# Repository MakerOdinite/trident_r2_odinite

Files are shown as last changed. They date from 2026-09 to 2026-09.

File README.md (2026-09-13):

# Trident R2 Odinite ⚙️

Trident LDO 300 cube mod build.

---

## What This Is

* **The Origin**: Years ago I bought an LDO Voron Trident 300 cube kit from Fabreeko.
* **The Delay**: Life happened and it sat in storage for a bit (3 and a half years is a bit, right?).
* **The Goal**: Figured it was time to build it, and mod it before I build—"do it nice, not twice." I want a stable printer for ABS, ASA, and multi-material printing.
* **The Solution**: Decided to go all-in on a Bondtech INDX system.
* **This Repo**: Born as a place for me to virtually build it before I really build it, and to serve as a permanent record of the build process.

---

## Submodules

* **[Official Voron Trident R2](https://github.com/VoronDesign/Voron-Trident)** (from 2026-06-26)  
  Commit: `f04f747d4dea06315806f352abf57f767cedf2b4`
* **[Clicky Clack Door](https://github.com/tanaes/whopping_Voron_mods.git)** (from 2024-08-26)  
  Commit: `62268ed817878e54d6a1186882060aa8368d4f0f`  
  *Hardware Kit:* [West3D Clicky Clack Fridge Door Kit](https://west3d.com/products/clicky-clack-fridge-door-kit-for-voron-trident-by-ldo-motors)

---

## Other Folders

**ldo_kit_info**: original build information regarding my base kit
**stealthpress_1s**: I'm going to do a lot of brass inserts... so I'm investing in this 

---

## Planned Mods & Hardware Changes

These changes were driven by what I had available and what I was able to source to support my stable ABS/ASA design goals:

| Category | Component / Mod Details |
| :--- | :--- |
| **Motion & Motors** | Change AB motors to longer shafts (`OMC 17HS19-2504S-H-V6`) |
| **Toolhead** | Bondtech INDX with 7 tools |
| **Enclosure & Frame** | ACM panels, titanium rail backers, and PEEK Z-axis lead screw nuts |
| **Cooling & Filtration** | Stealthmax V2 (top intake, bottom recirculation), dual 120mm underbed chamber circulators, and active AB stepper coolers |
| **Electronics & Power** | BTT Manta M8P V2 MCU, Raspberry Pi CM5 (with copper heatspreader, a 4011 heatsink, and custom fan cooling), Mean Well RSP-320-24 PSU, and BTT TMC5160 Pro stepper drivers (cooled with 5015 Delta fans) |
| **User Interface & Misc** | BTT HDMI5 touchscreen, chamber LEDs, and "Rock and Roller" mod for easy bottom access |

---

## Mods Considered (and Passed On)

* **Inverted Electronics Bay**: Passed on this because I didn't want loose parts or debris falling down directly into the electronics bay during maintenance.

---

## TODO

- [ ] Double-check endstops (prefer mechanical, normally closed `NC` fail-safe wiring, Omron, no lever)
- [ ] Install Chamber LEDs and status light bar
- [ ] Design/print a custom Tophat to clear the PTFE tubes
- [ ] Design/mount a camera mount
- [ ] Configure ethernet over Wi-Fi

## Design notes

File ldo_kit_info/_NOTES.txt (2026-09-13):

LDO kit matches a batch 2 release, without included Pi and 32GB sd card instead of 16GB.

Minimized pdf with ghostscript:
gs --% -sDEVICE=pdfwrite -dCompatibilityLevel=1.4 -dColorConversionStrategy=/LeaveColorUnchanged -dBlendConversionStrategy=/None -dDownsampleColorImages=true -dDownsampleGrayImages=true -dDownsampleMonoImages=true -dColorImageResolution=300 -dGrayImageResolution=300 -dMonoImageResolution=300 -dColorImageDepth=-1 -dGrayImageDepth=-1 -dMonoImageDepth=-1 -dAutoFilterColorImages=false -dAutoFilterGrayImages=false -dColorImageFilter=/FlateEncode -dGrayImageFilter=/FlateEncode -dNOPAUSE -dQUIET -dBATCH -sOutputFile="LDO Voron Trident 300 Wiring Guide (Rev. A_C) _ LDO Documentation.pdf" "LDO Voron Trident 300 Wiring Guide (Rev. A_C) _ LDO Documentation_big.pdf"

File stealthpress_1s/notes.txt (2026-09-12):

downloaded on 2026-09-12 from:
https://www.printables.com/model/1081157-stealth-press-1s-heat-set-insert-press

converted to make video much smaller:
ffmpeg -i '.\Stealth Press 1S build guide [reMUZEUkHd0].webm' -vf "scale=-2:480" -r 30 -c:v libx265 -preset slow -crf 26 -pix_fmt yuv420p -c:a aac -ar 16000 -b:a 48k stealthpress1s_assembly.mp4

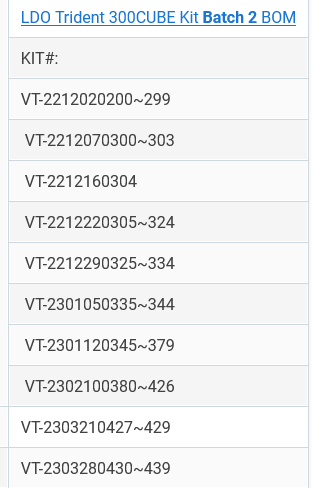
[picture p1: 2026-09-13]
ldo_kit_info/serial_batch_match_vt-2301120373.png

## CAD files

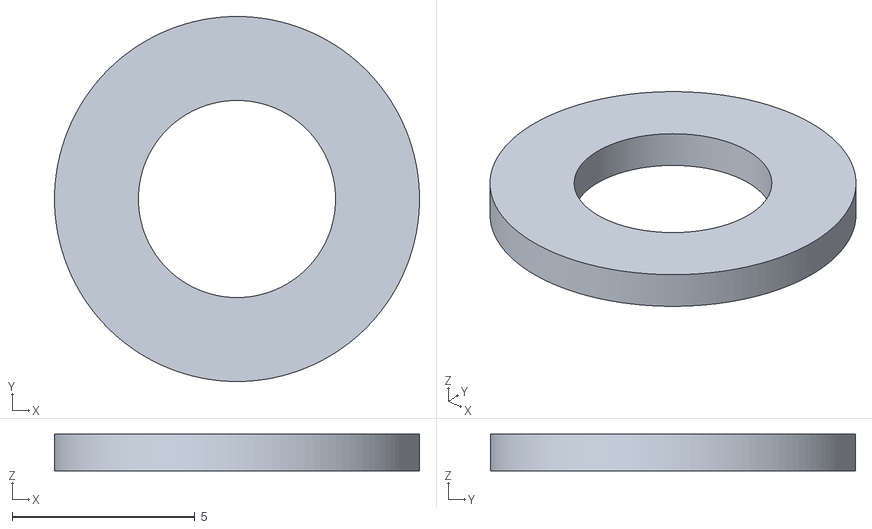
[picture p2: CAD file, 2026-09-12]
stealthpress_1s/stl from printables/a_m5_1mm_spacer_x4_r1s.stl
10.00 x 10.0 x 1.00

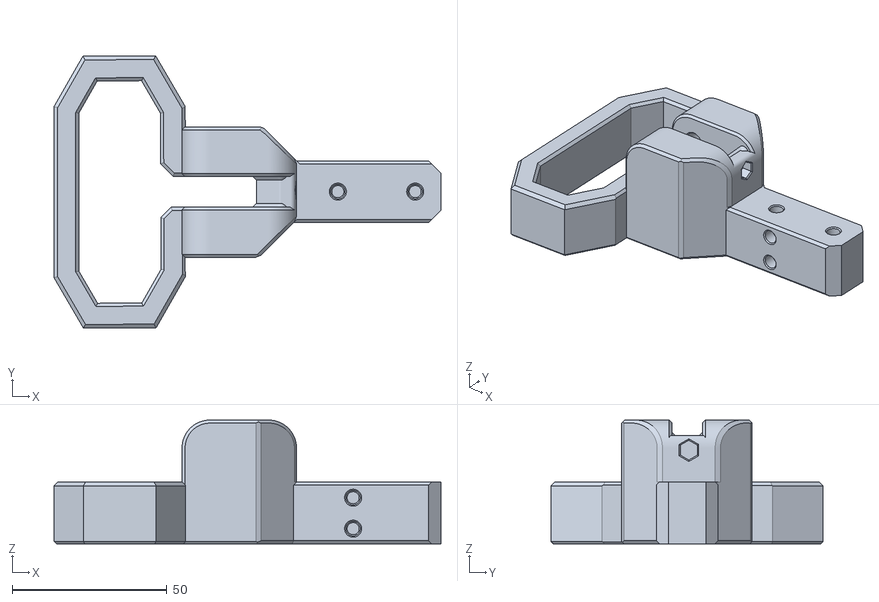
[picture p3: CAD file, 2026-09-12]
stealthpress_1s/stl from printables/top_handle_x1_r1s.stl
125.1 x 88.0 x 40.0

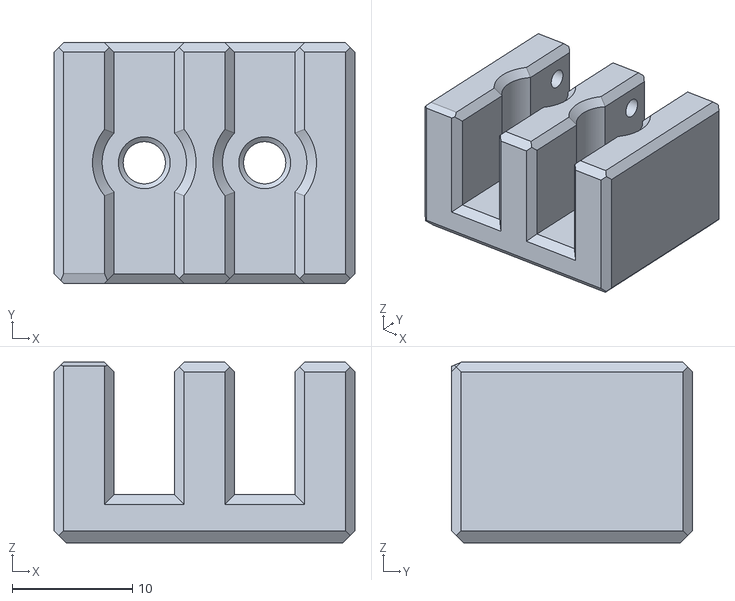
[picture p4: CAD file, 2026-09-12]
stealthpress_1s/stl from printables/a_strain_relief_r_x1_r1s.stl
25.0 x 20.0 x 15.0

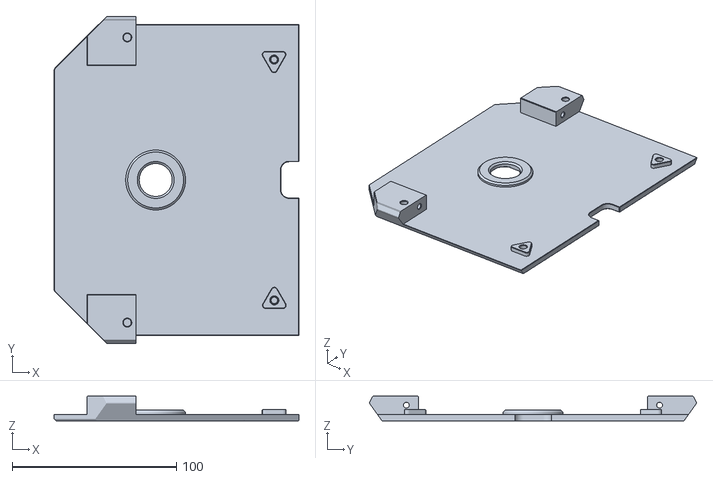
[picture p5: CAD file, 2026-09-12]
stealthpress_1s/stl from printables/buildplate_x1_r1s.stl
149.0 x 199.0 x 15.0

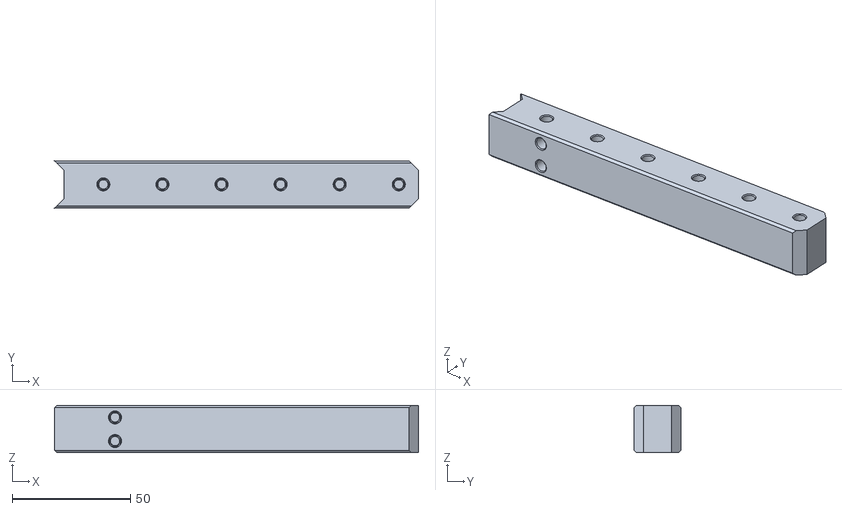
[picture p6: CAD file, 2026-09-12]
stealthpress_1s/stl from printables/center_x1_r1s.stl
154.0 x 20.0 x 20.0

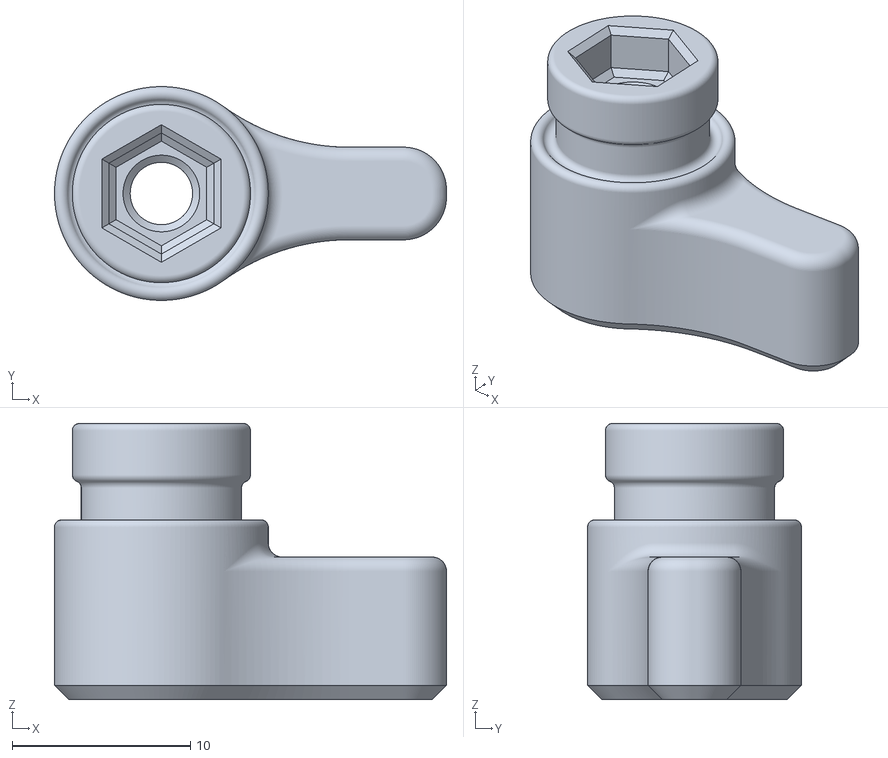
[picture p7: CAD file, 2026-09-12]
stealthpress_1s/stl from printables/a_soldering_iron_mount_knob_x1_r1s.stl
22.0 x 12.0 x 15.5

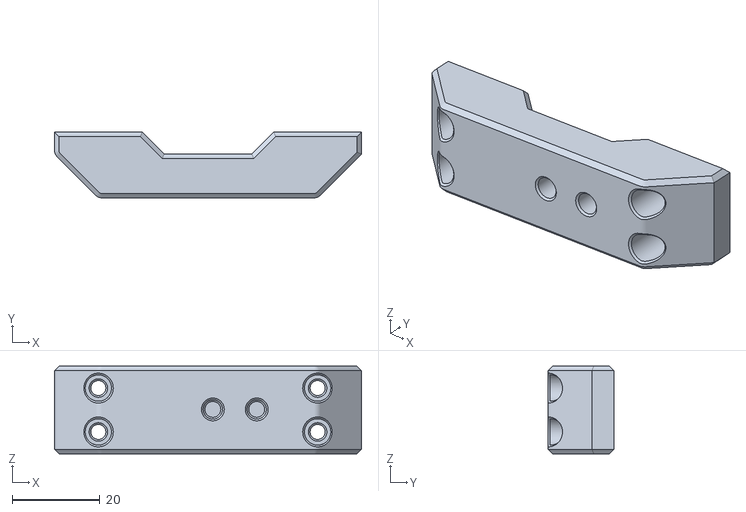
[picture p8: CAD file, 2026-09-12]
stealthpress_1s/stl from printables/support_arm_l_x1_r1s.stl
70.0 x 15.0 x 20.0

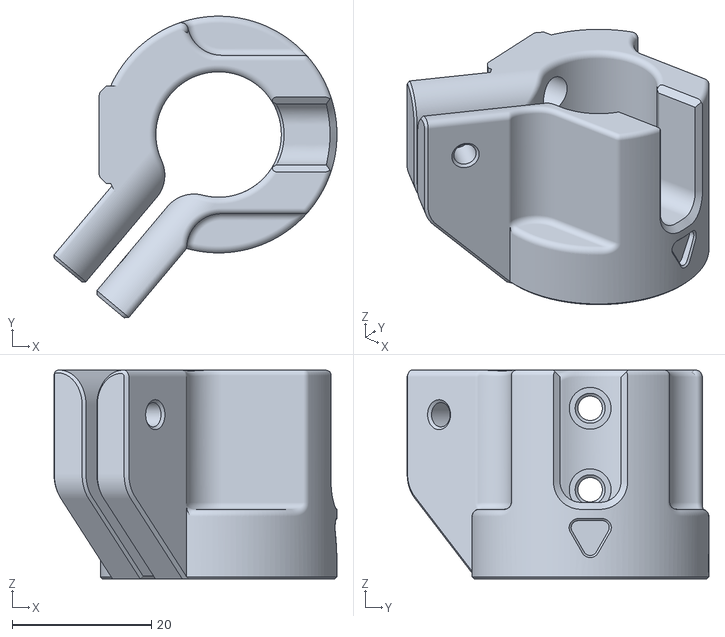
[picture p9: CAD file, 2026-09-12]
stealthpress_1s/stl from printables/soldering_iron_mount_generic_id18_x1_r1s.stl
40.6 x 43.3 x 30.0

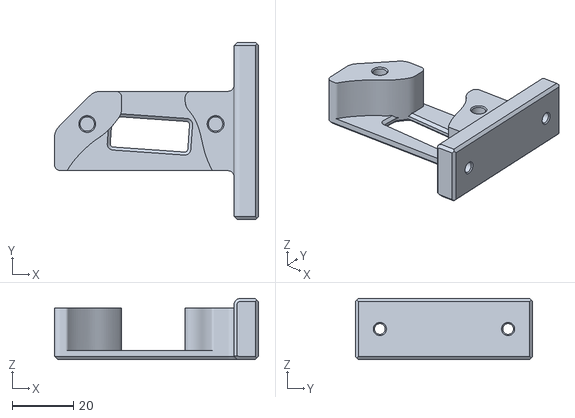
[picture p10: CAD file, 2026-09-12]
stealthpress_1s/stl from printables/keybak_plate_b_x1_r1s.stl
66.8 x 58.0 x 20.0

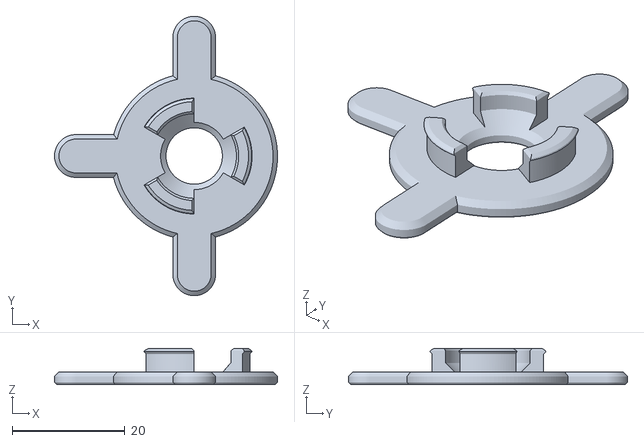
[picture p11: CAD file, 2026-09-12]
stealthpress_1s/stl from printables/a_buildplate_bushing_open_x1_r1s.stl
39.6 x 49.6 x 6.40

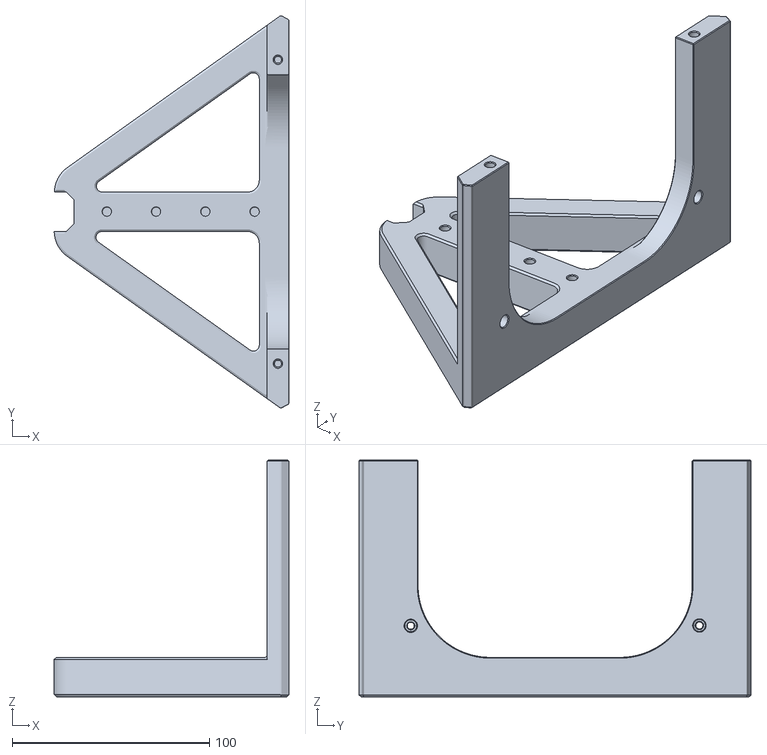
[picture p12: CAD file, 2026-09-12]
stealthpress_1s/stl from printables/leg_x1_r1s.stl
119.1 x 198.9 x 120.0

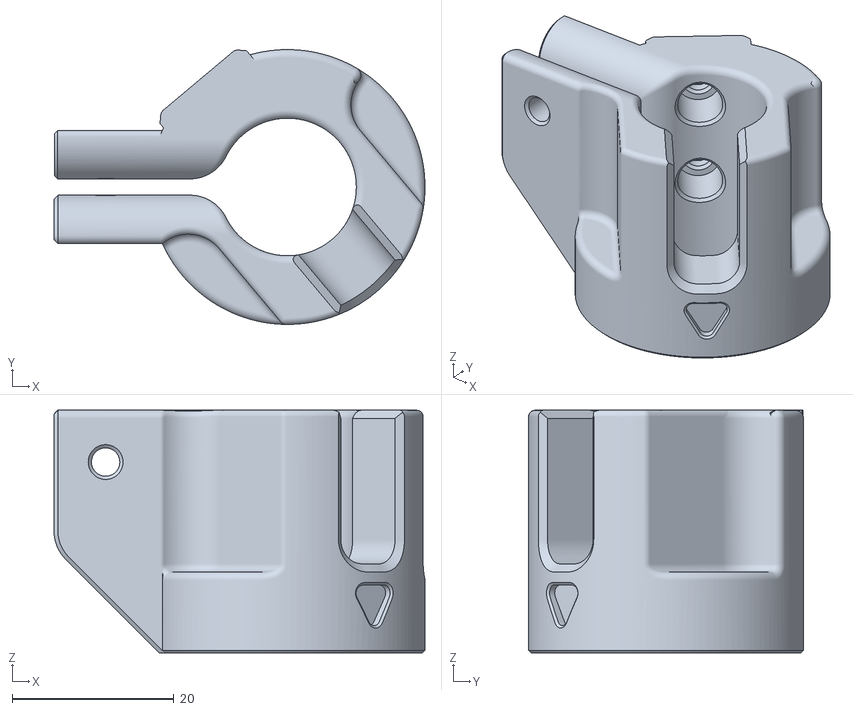
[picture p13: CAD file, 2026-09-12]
stealthpress_1s/stl from printables/soldering_iron_mount_generic_id17_x1_r1s.stl
45.9 x 34.0 x 30.0

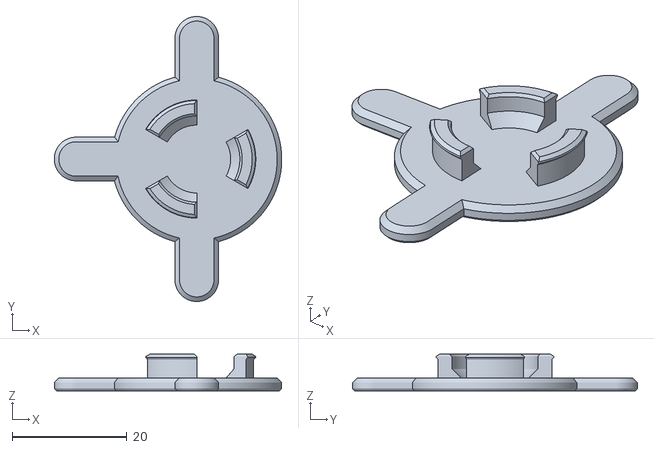
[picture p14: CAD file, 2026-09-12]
stealthpress_1s/stl from printables/a_buildplate_bushing_closed_x1_r1s.stl
39.6 x 49.6 x 6.40

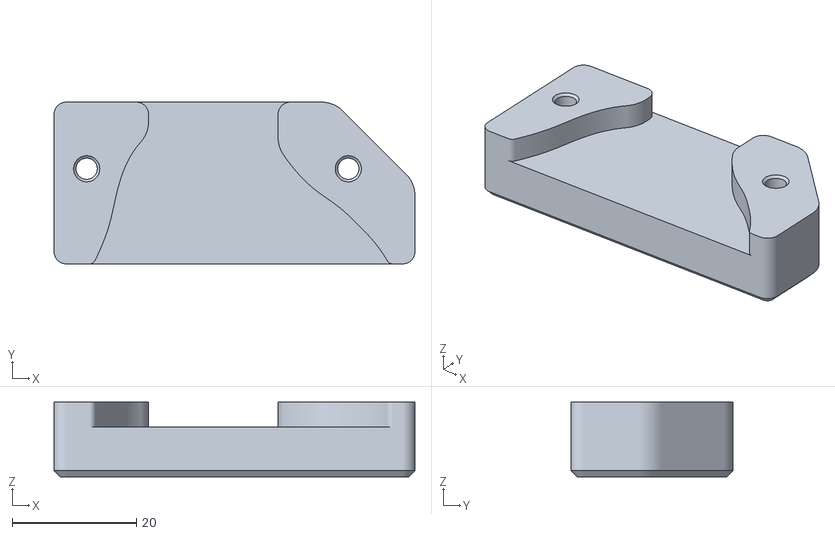
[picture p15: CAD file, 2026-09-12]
stealthpress_1s/stl from printables/keybak_plate_a_x1_r1s.stl
58.0 x 26.0 x 12.0

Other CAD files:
stealthpress_1s/stl from printables/support_arm_r_x1_r1s.stl
stealthpress_1s/stl from printables/soldering_iron_mount_generic_id19_x1_r1s.stl
stealthpress_1s/stl from printables/soldering_iron_mount_generic_id16_x1_r1s.stl
stealthpress_1s/stl from printables/soldering_iron_mount_generic_id15_x1_r1s.stl
stealthpress_1s/stl from printables/a_strain_relief_l_x1_r1s.stl
stealthpress_1s/stl from printables/arm_x1_r1s.stl
stealthpress_1s/stl from printables/soldering_iron_mount_generic_id20_x1_r1s.step
stealthpress_1s/stl from printables/soldering_iron_mount_generic_id20_x1_r1s.stl
stealthpress_1s/stl from printables/soldering_iron_mount_pine_x1_r1s.stl
stealthpress_1s/stl from printables/soldering_iron_mount_ts100_x1_r1s.stl

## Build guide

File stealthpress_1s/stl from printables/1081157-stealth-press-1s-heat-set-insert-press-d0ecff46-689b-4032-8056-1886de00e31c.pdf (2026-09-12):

## Stealth Press 1S — heat set insert

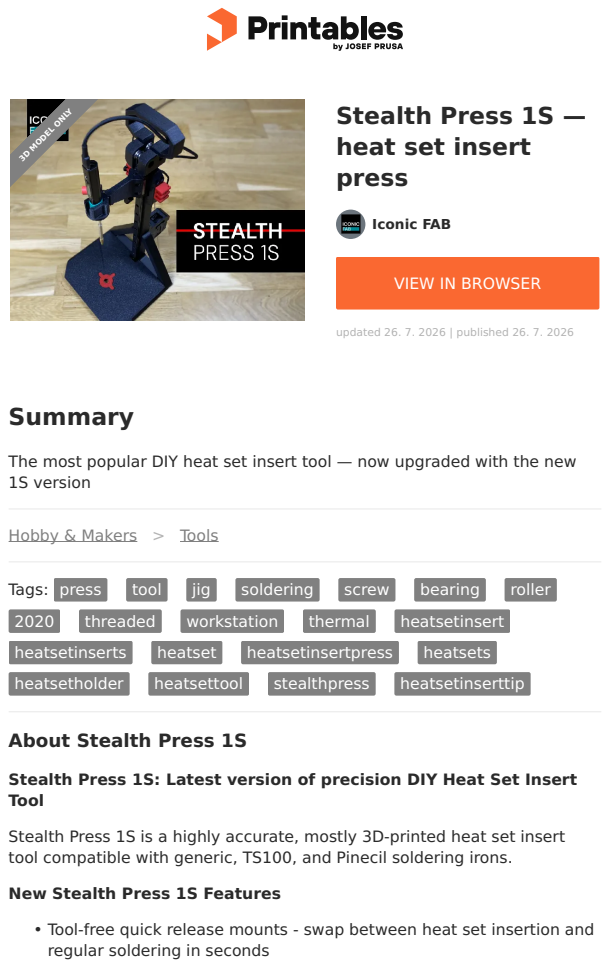
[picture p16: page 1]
Summary; Tags:; press; tool; jig; soldering; screw; bearing; roller; threaded; workstation; thermal; heatsetinsert; heatsetinserts; heatset; heatsetinsertpress; heatsets; heatsetholder; heatsettool; stealthpress; heatsetinserttip; Iconic FAB; updated 26. 7. 2026 | published 26. 7. 2026; 3D MODEL ONLY

VIEW IN BROWSER (https://www.printables.com/model/1081157-stealth-press-1s-heat-set-insert-press)

The most popular DIY heat set insert tool — now upgraded with the new
1S version

Hobby & Makers (https://www.printables.com/model?categoryId=48) > Tools (https://www.printables.com/model?categoryId=49)

About Stealth Press 1S

Stealth Press 1S: Latest version of precision DIY Heat Set Insert
Tool

Stealth Press 1S is a highly accurate, mostly 3D-printed heat set insert
tool compatible with generic, TS100, and Pinecil soldering irons.

New Stealth Press 1S Features

Tool-free quick release mounts - swap between heat set insertion and
regular soldering in seconds

Interchangeable build plate inserts (open/closed designs) for better small part handling
Built-in carrying handle for improved portability

Optional storage drawer (https://www.printables.com/model/1087555-drawer-add-on-for-stealth-press-1s) keeps soldering tips and heat set inserts organized — download here. (https://www.printables.com/model/1087555-drawer-add-on-for-stealth-press-1s)

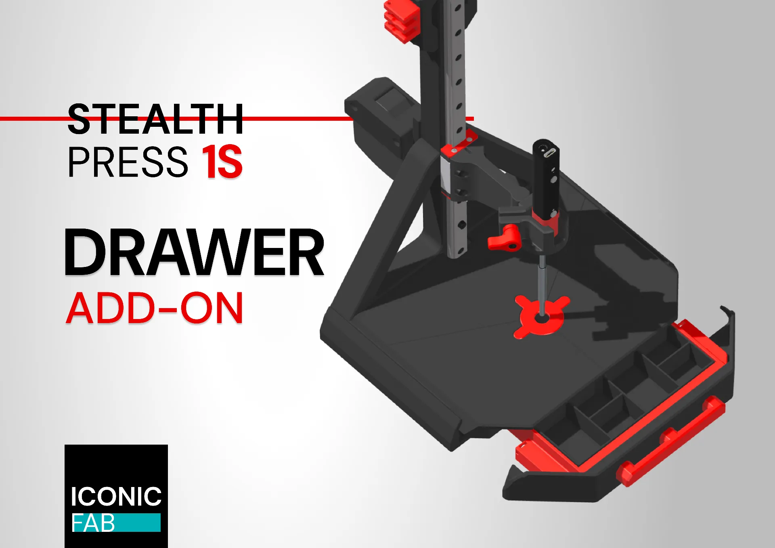
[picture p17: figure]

Core Benefits:

Professional precision by 300mm MGN12H linear rail Integrated printable build plate
Flexible retraction options - premium KEY-BAK or cost-effective alternatives
Innovative design improvements over similar DIY solutions Professional results without expensive components
Bill of Materials and Sourcing guide

Buy kits

Vendor | Kit version | Product page | Region
KB3D.com | 1S | Buy here (https://kb-3d.com/store/tools-equipment/1002-pre-order-iconic-fab-stealth-press-kit-for-heat-set-inserts-1698787283366.html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) | US

•

•

•
•
•

•
•

Veetec3D | 1S | Buy here (https://veetec3d.etsy.com/listing/1882637705/stealth-press-s1-precision-heat-set) | EU, INT
DREMC | 1S | Buy here (https://store.dremc.com.au/products/iconic-fab-stealth-press-hardware-kit-for-heat-set-inserts-1s) | AU
Blurolls3D.com | 1 | Buy here (https://www.blurolls3d.com/products/blurolls-stealth-press-heat-kit-insert-press-tool-soldering-iron-tip-thread-heat-insert-nut-embedded-m2-m8-for-3d-printed-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) | INT
Blurolls [on AliExpress] | 1 | Buy here (https://s.click.aliexpress.com/e/_c4sZFUCB) | INT
Toaiot [on AliExpress] | 1 | Buy here (https://s.click.aliexpress.com/e/_c4ts9KEj) | INT

R1 kits are almost fully compatible with R1S version, except 1 bolt and 1 nut, see Bill of Materials below for details.

Self sourcing guide

Part | Size / Standard | QTY Source
M3 bolts | M3x8 SHCS | 40 | Buy here (https://s.click.aliexpress.com/e/_c45s7am7)
M3 bolt [1] | M3x25 (or 30) SHCS | 1 | Buy here (https://s.click.aliexpress.com/e/_c3bW5aPz)
M3 nut [2] | M3 | 1 | Buy here (https://s.click.aliexpress.com/e/_c2ycWcVD)
M5 bolts | M5x25 SCHS | 2 | Buy here (https://s.click.aliexpress.com/e/_c3qhsyCf)
Bearings (F = flanged) | F695-2RS | 4 | Buy here (https://s.click.aliexpress.com/e/_c3TFYhux)
M3 threaded heat set inserts (M3*OD: 5*L:4) | M3x5x4 | 30 | Buy here (https://s.click.aliexpress.com/e/_c3dvw9YL)

Linear rail with bearing | MGN12H 300mm | 1 | Buy here (https://s.click.aliexpress.com/e/_c44HZLCx)
Retractable device (Key-Bak®) | Super48 36" 13oz | 1 | Buy here (https://amzn.to/49czQRI)
Retractable device (Budget savvy alternative) | 500g version | | Buy here (https://s.click.aliexpress.com/e/_c3Yek5OB)

Notes for R1S Bill of Materials

[1] [2] — 1x M3x25 (or 30) SHCS bolt and 1 x M3 nut is only parts difference between R1 and R1S versions.

Soldering irons and adapters

Soldering irons (supported variations) | Type | Source
Variation 1 | Generic | Buy here (https://s.click.aliexpress.com/e/_c4aUy6Ib)
Variation 2 | TS100 | Buy here (https://s.click.aliexpress.com/e/_c4PlLCXH)
Variation 3 | Pinecil | Buy here (https://s.click.aliexpress.com/e/_DF12xxz)
Heat insert adapters and tips | Type | Source
Soldering iron adapters and Tips (Generic) | Generic | Buy here (https://s.click.aliexpress.com/e/_c2uUMh2R)
Soldering iron adapters and Tips (TS100 or Pinecil) | TS100 or Pinecil | Buy here (https://s.click.aliexpress.com/e/_c3diugPz)

Alternative versions and add-ons

Download printed parts for Budget savvy retractable device alternative (https://www.printables.com/model/779386-not-a-key-bak-mount-for-stealth-press-heat-set-ins)

Drawer add-on (https://www.printables.com/model/1087555)

Assembly manual

There is no specific Stealth Press 1S assembly manual at this time. However, assembly for Stealth Press 1S is fairly similar to version Stealth Press 1.

Download Stealth Press 1 assembly manual with visuals and a step-by-step guide, (https://files.printables.com/media/prints/609644/other_files/4843265_e59cfc31-fcd8-4017-8f65-f14361245270_7bd9886b-26d0-468e-92d9-ef99138e9d90/stealth_press_a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) or;
Follow instructions Iconic FAB's Stealth Press 1S video build guide. (https://youtu.be/reMUZEUkHd0)
Video build guides

Iconic FAB video build guide (for 1S)

https://www.youtube.com/watch?v=reMUZEUkHd0

Other build guides (for version 1)

Live build by Nero3D (for v1) — Heatset Press and Fixing things (https://www.youtube.com/watch?v=G3Zb9F8HbCo&t=3s) Live build by ModBotArmy (for v1) — Building The Stealth Press Heat Insert Tool! (https://www.youtube.com/watch?v=mqJDLKIEuqs)
Supported soldering irons

Generic, (https://s.click.aliexpress.com/e/_c4aUy6Ib) TS100 (https://s.click.aliexpress.com/e/_c4PlLCXH) or Pinecil. (https://s.click.aliexpress.com/e/_DF12xxz)
Print guidelines

Here are print guidelines for you to follow in order to have decent success with printing parts:

3d printing process | FDM (fused deposition modeling)
Infill type | Support cubic, Grid, Gyroid, Honeycomb, Triangle or Cubic

•

•

•
•

Material | ASA, ASA-CF, ABS, ABS+, ABS-CF [1]
Infill percentage | 25 - 60% [2]
Layer height | 0.2mm, recommended
Wall count | Recommended: 4
Solid top/bottom layers | Recommended: 5
Extrusion width | 0.4mm, recommended

Side notes to the print guidelines

[1] PLA, PLA+, and PETG are also considerable filament choices. However, take into account that soldering iron radiates some indirect heat. The usage of less temperature-stable filaments may result in part deformations over time. It is recommended to use PETG ir ideally - ASA or ABS at least for “arm” and “iron mount” parts.
[2] Consider using 60% ot more of infill for build plate part to ensure it's not sagging over time and 25-40% for all other parts.

A wall count of 4 is an absolute must to ensure the structural integrity of the parts.
File naming for printed parts

The parts use this naming convention:

Primary color | These files will have nothing at the start of the filename. Example: buildplate_x1.stl
Accent color | Files have “[a]” to the front of any STL file that is intended to be printed with accent color. Example: [a]_bushing_x1.stl

Count of parts | Files have “x1” to “x4” at the end of any STL file. The number represents the count of identical parts to be printed. Example: [a]_m5_1mm_spacer_x4 (In this case you will need to print 4 identical spacers).
Revision number | Files have i.e. “_r1s” suffix at the end of any STL file. This number is file revision number.

How to support the project

Here are most popular choices how to do so:

Consider becoming member of Iconic FAB Club (https://www.printables.com/@IconicFAB/) on Printables and get all Paid models and Manuals for single membership fee, starting from as low as $3.
Press like and download model files. It helps more than I can express.
Special thanks

To @joshmurrah (https://www.printables.com/@joshmurrah_539268) for ginormous assistance in testing and improvements for 1S version and generally being amazing human being
To @radicalreel (https://www.printables.com/@radicalreel) for his version 1 mod and inspiration for carrying handle
To @3DPMAMSIH (https://www.printables.com/@3DPMAMSIH) for his version 1 drawer mod and ideas which lead to creating proprietary drawer add-on for 1S version.
To all great 3DP community building project, posting comments and makes, following me in social media and supporting what I do in so many amazing ways.
Credits and acknowledgements

Here is the list of other open-source projects used for sourcing multiple CAD parts.

Listed models below are modified to fit the project purpose and design:

VORON Switchwire: https://github.com/VoronDesign/Voron-Switchwire [Base for remix of KEY-BAK mounting parts]
Ender SW: https://github.com/boubounokefalos/Ender_SW [Base for remix of Support arms]

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
## Model files

Change log

Date | Changes
03.12.2024 soldering_iron_mount_generic_ID18_x1_r1s.stl — updated to | correct ID size of 18mm

26.11.2024 R1S release

top_handle_x1_r1s.stl

center_x1_r1s.stl

leg_x1_r1s.stl

buildplate_x1_r1s.stl

a_buildplate_bushing_closed_x1_r1s.stl

a_buildplate_bushing_open_x1_r1s.stl a_strain_relief_r_x1_r1s.stl

a_strain_relief_l_x1_r1s.stl

support_arm_l_x1_r1s.stl

support_arm_r_x1_r1s.stl

arm_x1_r1s.stl

keybak_plate_a_x1_r1s.stl

keybak_plate_b_x1_r1s.stl

a_m5_1mm_spacer_x4_r1s.stl

a_soldering_iron_mount_knob_x1_r1s.stl

soldering_iron_mount_ts100_x1_r1s.stl

- STEP file for generic soldering iron mount (20mm ID)

## License

This work is licensed under a GNU (https://www.gnu.org/licenses/gpl-3.0.html)

soldering_iron_mount_pine_x1_r1s.stl

soldering_iron_mount_generic_id20_x1_r1s.stl

soldering_iron_mount_generic_id19_x1_r1s.stl

soldering_iron_mount_generic_id18_x1_r1s.stl

soldering_iron_mount_generic_id17_x1_r1s.stl

soldering_iron_mount_generic_id16_x1_r1s.stl

soldering_iron_mount_generic_id15_x1_r1s.stl

soldering_iron_mount_generic_id20_x1_r1s.step

General Public License v3.0 (https://www.gnu.org/licenses/gpl-3.0.html)

✖ | Sharing without ATTRIBUTION
✔ | Remix Culture allowed
✔ | Commercial Use
✔ | Meets Open Definition
ℹ | Share under the same license

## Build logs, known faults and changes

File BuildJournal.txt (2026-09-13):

2026_09_13

Started pulling and cross referencing the original LDO kit documentation. I will need to pay close attention to which parts to print. I'm concerned about the z chain belt and exactly what parts aren't needed. There is also a difference in deck panel thickness to be aware of. Virtual build should solve these issues!

Came across an interesting mod.... now I'm curious if I should attempt CNC some parts out of aluminum at work (AB motor mounts, XY Joints with Live Idlers). In general I've always preferred a pin over a screw for any rotational axle.

https://www.printables.com/model/1755070-voron-trident-r2-pinned-gantry-and-live-idler-xy-j/files

LDO kit matches a batch 2 release, without included Pi and 32GB sd card instead of 16GB.

-------------------------------------------------
2026_09_12

Spent hours on and off previous weeks figuring out how I was going to build this. I do not necessarily recommend any of these changes for you, they are where my research led me after considering previous failures on other printer builds and modifications, what parts were available to me, and what parts I was able to source. Long story short, these were my priority upgrades:
  * trap nuts replace with PEEK due to known issue
  * want a heated chamber for ABS and ASA, this led to:
    + trident r2 supports a longer shaft, went to a 1.8deg stepper, class h for AB motors. (OMC 17HS19-2504S-H-V6)
    + higher current rating, lower resistance and lower inductance, so upgrade from TMC2209 to TMC5160 Pro
    + Gates EDPM high temp belts
    + As long as we've gone this far, might as well "belt-and-suspenders" motor cooling (my primary failure on previous printers) and add 40x40x11 aluminum heatsinks with a fan
  * Clicky Clack door
  * Stealthmax V2 recirculation filtration
  * ACM panels
  * I will need custom designed top hat to have space for the Bondtech INDX (7 tools) and PTFE tubes. Also clearance for stealthmax V2
  * industrial fans (e.g. Delta)
  * minimize electronics in the bottom bay --> manta m8p v2.0, cm5, btt hdmi5 screen
    + needed to cool cm5.... going to attempt a copper heat spreader with aluminum fins and an axial fan if space allows.
  * minimize potential issues with power --> use a meanwell RSP psu

Spent time figuring out how I'm going to assemble my virtual build. I will standardize on Solidworks (as that is where most my experience is). How to download fusion 360 so I can export f3d files to step. I will provide a final assembly in step as well.

Added the official trident r2 as a submodule and the clicky clack door. I will be using the Stealthpress 1S in this build, but there is not a repo (only a Printables page). So I added to a folder along with the GPL_v3 license. I will do my best to add licenses on work or parts I use to derive new parts.

Spent time organizing parts, removing the ones I don't plan on using, and adding in the ones I will. My ultimate goal is to organize an assembly with the parts I have on hand for each step of the build, then build it physically with my virtual build as reference.

Today I replaced trap nuts with PEEK. Wow, the stock nuts (never used) were very loose and already had wear (dust present).... this was a known issue, but I was quite surprised at the initial state of it! Spent time wiping down the z axis carefully with IPA, then installed new ones. First two were tight but easy. The last one has very snug and I didn't want to bend the rod. Turns out, spraying with some IPA (top and bottom) was enough to get it going.

NOTE FOR BUILD: put the stiffer z (near hinge of box) as the central z axis motor.
